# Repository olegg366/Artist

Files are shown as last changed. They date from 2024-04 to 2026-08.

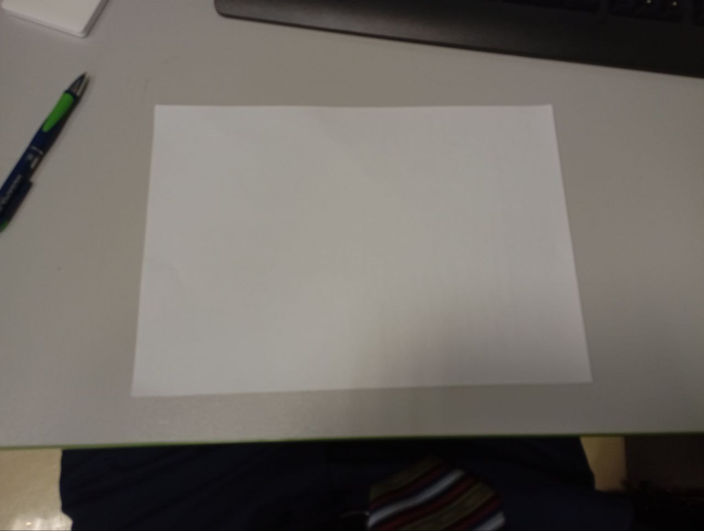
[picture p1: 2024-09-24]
images/paper1.jpg

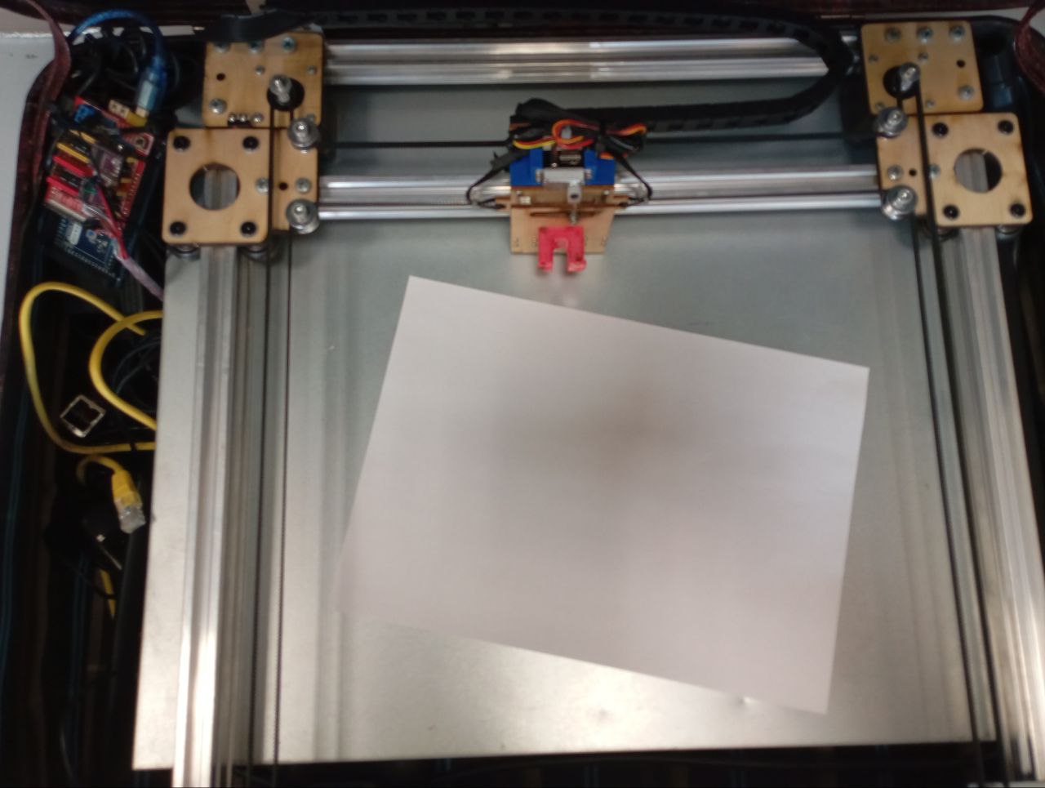
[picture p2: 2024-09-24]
images/paper.jpg

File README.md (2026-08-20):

# Робот-художник с искусственным интеллектом

Робот на базе координатного плоттера (кинематика H-bot), который распознаёт жесты и голос пользователя, генерирует изображение по наброску и текстовой подсказке (Stable Diffusion + ControlNet) и рисует его маркером на бумаге. Устройство собрано в корпусе чемодана.

Проект выполнен в рамках Всероссийской олимпиады школьников (профиль «Робототехника», технология/труд), ГБНОУ «Президентский ФМЛ №239». Полная пояснительная записка — в [`docs/`](docs).

---

## Идея

Пользователь рисует пальцем в воздухе набросок и произносит тему открытки. Робот:

1. по видео с камеры распознаёт кисть руки и жесты (без каких-либо контроллеров/перчаток — только компьютерное зрение);
2. переводит траекторию пальца в линию на холсте;
3. распознаёт голосовую подсказку и переводит её на английский;
4. генерирует по наброску и тексту 3 варианта изображения нейросетью img2img (Stable Diffusion 1.5 + ControlNet-Scribble);
5. превращает выбранное растровое изображение в непрерывную траекторию заливки контуров, которую физически можно нарисовать одним маркером;
6. рисует получившуюся открытку на листе А5 плоттером, отслеживая, не мешает ли этому процессу рука человека в рабочей зоне.

В проекте задействованы: компьютерное зрение реального времени, классификация жестов собственной нейросетью, генеративная модель (Stable Diffusion), C++-модуль для расчёта траектории закраски растра, интеграция C++/Python через `ctypes`, прошивка ЧПУ (Marlin) и GUI на tkinter.

---

## Аппаратная часть (кратко, для понимания контекста ПО)

Структурная электрическая схема — [`docs/Э1.png`](docs/Э1.png).

- **Вычислительный блок**: Intel Core i5, NVIDIA GeForce RTX 3060 (12 ГБ VRAM, обязательна для инференса Stable Diffusion в разумное время), подключена через выносной модуль (ADT-Link UT3G, Thunderbolt/PCIe extender) — компьютер и видеокарта физически разнесены внутри чемодана.
- **Плоттер**: рама на алюминиевом конструкционном профиле, кинематика **H-bot** (позаимствована и адаптирована из открытой 3D-модели принтера, ось Z удалена — печатающая головка держит маркер и сервопривод его подъёма/опускания), 2 шаговых мотора Nema17 (42SHDC3025-24b) через драйверы DRV8825.
- **Контроллер плоттера**: Arduino Mega + Protoneer CNC Shield V3, прошивка — форк **Marlin** (см. [`Marlin/`](Marlin)), команды отправляются по serial в формате G-code.
- **Определение уровня маркера**: оптический концевой выключатель + автокалибровка угла сервопривода (см. `Plotter.calibrate_servo` в `plotter.py`).
- **Зрение**: 2 камеры Logitech HD 1080p (одна следит за рукой пользователя, другая — за рабочей зоной плоттера/бумагой), RTSP/локальный видеопоток.
- **Питание**: аккумулятор 6S1P 16000 мАч + понижающие преобразователи напряжения.
- Механика и корпус спроектированы в КОМПАС-3D (`models/`, `plans/`, `Machine.stp`), детали — лазерная резка фанеры + 3D-печать.

---

## Структура ПО

Весь код, кроме одного модуля траектории, написан на **Python**; вычислительно критичный модуль генерации траектории заливки — на **C++**, скомпилирован в разделяемую библиотеку и вызывается из Python через `ctypes`. Такое разделение осознанное: ИИ-части нужна простота интеграции с экосистемой ML (PyTorch/TensorFlow/Keras), а геометрическому алгоритму — сырая производительность и доступ к параллелизму GPU.

### Модуль жестового управления

| Файл | Назначение |
|---|---|
| `gesture_recognizer.py` | Отдельный процесс: получает кадры с камеры, прогоняет через **MediaPipe HandLandmarker** (21 ключевая точка кисти) и через собственную обученную сеть-классификатор жестов. |
| `mlmodels/static.keras`, `convert_tensorrt.py` | Классификатор жестов: `Conv1D → Conv1D → Dense`, обучен на 20 эпохах на собственном датасете (см. `gen_ds.py`, `dataset/*.npy` — записи координат ключевых точек для жестов `open`/`ok`/`up`/`dislike`, собраны покадровым разбором отснятого видео). Дополнительно оптимизирован через **TensorRT SDK** (`convert_tensorrt.py`, `mlmodels/static_tftrt/`) для ускорения инференса на GPU. |
| `commander.py` | Конечный автомат высокого уровня, интерпретирующий последовательность жестов в действия: `Thumb_Up` — начать/закончить рисование или подтвердить выбор («да» в диалогах), `Thumb_Down` — отклонить вариант («нет»), `Pointing_Up` — переместить курсор, «щипок» большого и указательного пальца (порог по отношению межпальцевого расстояния к длине пальца) — «зажать» и вести линию (жест `Click` определяется отдельно от ML-классификатора чисто геометрически), `Open_Palm` ×2 — очистить холст. |
| `utilites.py` | Общие геометрические функции (расстояние между landmark'ами, отрисовка скелета кисти, линейная интерполяция координат камера → экран). |

Межпроцессное взаимодействие построено на `multiprocessing.Process/Queue/Value`: захват видео, распознавание жестов, генеративная нейросеть и GUI выполняются в **параллельных процессах**, синхронизированных через очереди и разделяемые примитивы, — иначе тяжёлый инференс диффузионной модели «заморозил» бы интерфейс.

Отдельная деталь: координата указательного пальца транслируется не напрямую в canvas, а в системный курсор мыши через `pyautogui` (`Commander.move`), а сама линия на холсте рисуется по отдельным командам (`set_start`/`draw_line`/`end_line`), отправляемым в GUI-процесс через очередь — canvas в `interface.py` намеренно не подписан на нативные события мыши tkinter, вся отрисовка идёт только через этот канал.

### Голосовой ввод

Распознавание речи и перевод реализованы прямо в `Commander.listen()` (`commander.py`): запись с микрофона через `speech_recognition`, распознавание русской речи (Google Speech API), перевод на английский через `googletrans` — для передачи в англоязычную по природе модель Stable Diffusion. Подтверждение распознанной фразы также идёт жестами (`Thumb_Up`/`Thumb_Down`) через тот же `move_while`, то есть голосовой и жестовый каналы переиспользуют одну и ту же логику ожидания. В репозитории также есть `google_speech.py` с похожей автономной функцией `recognize_and_translate` — в текущем пайплайне она не импортируется и не используется, судя по всему это более ранняя версия того же функционала.

### Генеративная нейросеть

`generator.py` — управление диффузионным пайплайном через библиотеку **`diffusers`**:

- **Stable Diffusion 1.5** + **ControlNet-Scribble** (`lllyasviel/sd-controlnet-scribble`) — набросок пользователя используется как структурное условие (contour-conditioning) генерации, а не просто как затравка, что даёт предсказуемую композицию итоговой картинки;
- планировщик **UniPCMultistepScheduler** — ускоренный сэмплер, позволяющий получить качественный результат за меньшее число шагов диффузии;
- **DeepCache** — кэширование промежуточных активаций UNet между шагами денойзинга для ускорения инференса;
- **tomesd** (Token Merging for Stable Diffusion) — слияние похожих токенов внимания, снижение вычислительной нагрузки без заметной потери качества;
- **xFormers** memory-efficient attention + `channels_last` memory format для UNet/VAE — оптимизация под конкретную архитектуру GPU;
- инференс выполняется на CUDA, весь пайплайн запущен в отдельном процессе, прогресс диффузии (шаг за шагом) прокидывается обратно в GUI через очередь для прогресс-бара.

Набор оптимизаций (DeepCache, tomesd, xFormers) выбран, чтобы уложить генерацию в приемлемое время на одной видеокарте с 12 ГБ видеопамяти при демонстрации вживую.

### Определение бумаги в рабочей зоне

`detect_paper.py` — компьютерное зрение поверх OpenCV/scikit-image: HSV-маскирование по цвету реперных зелёных меток на листе, поиск контуров, `minAreaRect` + сопоставление углов, перспективная трансформация (`warpPerspective`) для приведения снятого листа к прямоугольнику, повторное выделение внутренней зелёной рамки на выровненном изображении фильтром Канни для точного определения границ печатной области.

### Перевод изображения в траекторию плоттера

**Постановка задачи**: дано растровое бинарное изображение контуров (после `canny` + бинарная дилатация в `drawer.py`/`utilites.py`), нужно построить один непрерывный путь маркера конечной толщины `d`, который закрасит все контурные пиксели, минимизируя количество отрывов пера и лишних перемещений. По формулировке это близко к задачам покрытия зоны обхода (area coverage / Chinese postman) на нерегулярной области, для которых в общем случае нет простого точного решения за разумное время, поэтому используется эвристика.

**Алгоритм** (`trajectory.cpp`, экспортируется как `extern "C"` для вызова из Python):

1. Случайно выбирается стартовая точка, вокруг которой в радиусе `d/2` нет ни закрашенных, ни выходящих за рисунок точек.
2. Между текущей и следующей точкой строится путь (`get_path`), и вдоль всего пути закрашивается «дорожка» шириной `d` (имитация толщины реального маркера) — заливка выполняется BFS-подобным обходом (`fill_area`) с деками и посещённостью, а не наивным перебором пикселей.
3. Далее ищется следующая точка на расстоянии `d + 1` от текущей, удовлетворяющая тому же условию; если такой нет — берётся случайная валидная точка на изображении; если и такой нет — условие ослабляется (достаточно не выходить за границы исходной маски).
4. Цикл повторяется, пока не останется незакрашенных пикселей.
5. Результат — последовательность координат с маркерами разрывов (`±1e9`), которую `plotter.py` превращает в G-code, сшивая соседние фрагменты и вставляя команды подъёма/опускания пера между несвязными участками.

**Производительность и GPU-параллелизм.** При обработке реалистичных изображений число точек достаточно велико, чтобы наивная реализация на C++ работала медленно. Часть циклов переписана с использованием алгоритмов `std::execution`/`stdpar` (C++17), и модуль компилируется компилятором `nvc++` из NVIDIA HPC SDK с флагами `-stdpar -gpu=managed,cuda...,cc...` — стандартные алгоритмы STL (`transform`, `reduce`, `any_of`) в этом случае выполняются на GPU без написания CUDA-кернелов вручную. По оценке из пояснительной записки, это даёт прирост скорости на порядок по сравнению с однопоточным CPU-вариантом.

**Компиляция на лету.** `drawer.py::TrajectoryLib` сравнивает текущий исходник `trajectory.cpp` с сохранённой предыдущей версией (`lib/trajectory.prev`) и, если код изменился, перекомпилирует `.so`-библиотеку прямо во время работы программы (JIT-подобная схема разработки для C++/GPU кода).

**Мост Python ↔ C++.** Через `ctypes.CDLL` и `numpy.ctypeslib.ndpointer` с явной типизацией указателей (2D/3D массивы `float128`/`int32`) — передача сырых NumPy-буферов в скомпилированную библиотеку без копирования и без обёрточных биндингов вроде pybind11/Cython (в проекте также есть отдельные эксперименты с Cython, см. `tests/test_cython/`).

### Управление плоттером и прошивка

- `plotter.py` — класс `Plotter(serial.Serial)`: отправка G-code по последовательному порту с построчным подтверждением (`ok\n`), автокалибровка угла сервопривода по срабатыванию концевого выключателя, расчёт задержек между командами по фактической скорости подачи, а также **параллельный процесс безопасности** `HandChecker` — во время печати отдельный процесс детектирует руку человека в рабочей зоне через тот же MediaPipe-детектор и ставит печать на паузу, если пользователь потянулся к плоттеру.
- [`Marlin/`](Marlin) — используется прошивка **Marlin** (популярная прошивка для 3D-принтеров), сконфигурированная под кинематику **CoreXY/H-bot** и плату `PROTONEER_CNC_SHIELD_V3`, с урезанной осью Z (заменена на сервопривод пера).

### Интерфейс пользователя

`interface.py` — GUI на `tkinter`: собственные виджеты со скруглёнными углами и кастомной отрисовкой на `Canvas` (`RoundedFrame`/`RoundedButton`, ручное построение сглаженных многоугольников, авто-перенос текста по ширине виджета), полноэкранное окно с превью видео с камеры, индикатором состояния рисования (цветовой светофор), прогресс-баром генерации, попапом выбора толщины линии и блоком пошаговой инструкции по жестам для новых пользователей. Все тяжёлые операции (распознавание, генерация, печать) выполняются в фоновых процессах и общаются с GUI-процессом строго через очереди команд (`commands_queue`), что нужно, поскольку `tkinter` не является потокобезопасным.

### Обучение и вспомогательные ноутбуки

- `model.ipynb` — подготовка датасета жестов и обучение классификатора (`Conv1D`-архитектура на Keras/TensorFlow, `L2`-регуляризация), там же — эксперименты с настройкой пайплайна Stable Diffusion.
- `gen_ds.py` — сбор обучающей выборки: покадровое считывание landmark'ов руки с камеры и сохранение в `.npy`.
- `paper.ipynb`, `convert.ipynb` — вспомогательные эксперименты (отладка детекции бумаги, конвертации моделей).
- `draw_logo.py` — служебный скрипт печати заранее заданных изображений (например, логотипа) в обход основного пайплайна жестового ввода — использовался для тестирования плоттера отдельно от ИИ-части.

---

## Особенности реализации

- Захват видео, распознавание жестов, генерация изображения и GUI выполняются в отдельных процессах (`multiprocessing`), обмен данными — через очереди и разделяемые значения, а не напрямую.
- В проекте сочетаются разные модели вычислений: CUDA-инференс нейросетей (PyTorch/TensorRT), GPU-параллелизм через `stdpar`/`nvc++` в C++-модуле траектории, обычный CPU-код для CV и GUI.
- Обмен данными между Python и C++ идёт напрямую через `ctypes` и `numpy.ctypeslib.ndpointer`, без промежуточных биндинг-генераторов (pybind11/Cython); типы указателей и layout памяти согласуются вручную.
- Во время печати параллельно работает CV-детектор руки в рабочей зоне (`HandChecker`), который ставит плоттер на паузу при вторжении.
- Заливка контура маркером конечной толщины реализована собственным эвристическим алгоритмом (жадный обход ближайшей допустимой точки с постепенным ослаблением условий при тупике), а не сторонней библиотекой.
- Угол подъёма сервопривода пера определяется автокалибровкой по концевому выключателю при каждом запуске, а не задаётся константой в коде.

---

## Технологический стек

**Компьютерное зрение / ML:** MediaPipe (HandLandmarker), TensorFlow/Keras, TensorRT SDK, OpenCV, scikit-image (Canny, морфология, `regionprops`).

**Генеративный ИИ:** PyTorch, `diffusers` (Stable Diffusion 1.5, ControlNet), `tomesd`, `DeepCache`, `xFormers`, CUDA.

**Голос:** `SpeechRecognition` (Google Speech API), `googletrans`.

**Высокопроизводительные вычисления:** C++17, `std::execution`/`stdpar`, NVIDIA HPC SDK (`nvc++`), CUDA, `ctypes`.

**Механика/прошивка:** Marlin firmware, G-code, `pyserial`, Arduino Mega + CNC Shield.

**Интерфейс/инфраструктура:** `tkinter`, `multiprocessing`, NumPy, `pyautogui`, КОМПАС-3D (проектирование, вне репозитория кода).

---

## О запуске

Проект **не является «plug-and-play» приложением** и не предназначен для запуска на произвольной машине без соответствующего физического робота. Он поднимался в окружении, куда были заранее установлены и состыкованы по версиям, в частности:

- CUDA Toolkit и драйверы NVIDIA под конкретную видеокарту;
- PyTorch + `diffusers`/`transformers`/`accelerate` (с загрузкой весов Stable Diffusion 1.5 и ControlNet-Scribble из HuggingFace);
- TensorFlow/Keras + TensorRT SDK;
- MediaPipe с моделью `hand_landmarker.task`;
- NVIDIA HPC SDK (компилятор `nvc++`) для сборки C++/GPU-модуля траектории под конкретную вычислительную архитектуру GPU (`cc86`);
- OpenCV, scikit-image, `pyserial`, `SpeechRecognition`, `googletrans`, `pyautogui`, `webcolors` и другие Python-зависимости интерфейса;
- прошитая плата Arduino Mega с Marlin, физически подключённая по serial, и подключённые камеры/микрофон.

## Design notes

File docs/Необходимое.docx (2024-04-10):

1) Профили:
  a) 20*20*43 (https://www.soberizavod.ru/catalog/seriya_20_v_paz/profil_konstruktsionnyy_v20kh20_bez_pokrytiya/)3 х2
  b) 20*40*492 (https://www.soberizavod.ru/catalog/seriya_20_v_paz/profil_konstruktsionnyy_v20kh40_bez_pokrytiya/) х2
  c) 20*20*423 (https://www.soberizavod.ru/catalog/seriya_20_v_paz/profil_konstruktsionnyy_v20kh20_bez_pokrytiya/) х1
2) Уголки:
  a) 60*60 6 отв (https://www.soberizavod.ru/catalog/g_obraznye_seriya_20/g_soedinitel_60kh60_paz_6_otv_6_l61/?sphrase_id=325903) х8
3) Пластины:
  a) 40*60 6 отв (https://www.soberizavod.ru/catalog/pryamougolnye_seriya_20/soedinitel_40kh60_paz_6_m49/?sphrase_id=325904) х4
  b) Part2 (печать)
  c) Carriage (печать)
  d) Head holder (печать)
4) Подшипники и ролики:
  a) Ролики (https://www.soberizavod.ru/catalog/standartnye_2/standartnyy_plastikovyy_rolik_dlya_v_paza_a172/) х13
  b) Подшипники (https://www.soberizavod.ru/catalog/dlya_standartnykh_rolikov_1/podshipnik_dlya_standartnykh_rolikov_5_16_625zz_a181/) 23x
5) Шкивы:
  a) GT2 ширина 10 отверстие 5 (https://roboparts.ru/catalog/komplektuyushchie_dlya_3d_printera/shkivy/gt2-10mm-20-zubov-d-5mm/) х2
  b) GT2 ширина 10 отверстия 5 без скруглений (https://roboparts.ru/catalog/komplektuyushchie_dlya_3d_printera/shkivy/shkiv-gt2-v2-20-zubov-10mm-d-5mm/) х2
  c) GT2 ширина 6 отверстие 5 гладкие (https://roboparts.ru/catalog/komplektuyushchie_dlya_3d_printera/shkivy/rolik-gt2-6mm-h-type/) х4
6) Моторы: Nema17 х2
7) Крепление:
  a) Т-болт х48
  b) Т-гайки М5 (https://www.soberizavod.ru/catalog/t_bolty_i_t_gayki_paz_6/t_gayka_m5_paz_6_a130/) 60x
  c) Т-гайки М4 (https://www.soberizavod.ru/catalog/t_bolty_i_t_gayki_paz_6/t_gayka_m4_paz_6_a129/) 10х
  d) Т-гайки М3 (https://www.soberizavod.ru/catalog/t_bolty_i_t_gayki_paz_6/t_gayka_m3_paz_6_a128/) 10х
  e) Винты для Т-гаек (https://www.soberizavod.ru/catalog/m5_2/vint_s_polukrugl_gol_i_vn_shestigr_otsink_m5_kh_8_iso_7380_1_a523/) 60x
  f) Винты для крепления шкивов (https://www.soberizavod.ru/catalog/m5_1/vint_tsilindr_s_vnutrennim_shest_m5_kh_25_din_912_k83/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) 10х
  g) Шайбы 5 (https://www.soberizavod.ru/catalog/obychnaya_shayba/shayba_5_otsink_din_125_k44/?sphrase_id=336375) 30х
  h) Шайбы для роликов (https://www.soberizavod.ru/catalog/shayby_vysokotochnye_distantsionnye_1/vysokotochnaya_distantsionnaya_shayba_5_mm_a211/) х12
  i) Втулки для роликов (https://www.soberizavod.ru/catalog/vtulki_distantsionnye_dlya_vinta_m5/distantsionnaya_vtulka_5kh6_mm_a201/) х15
  j) Винты для роликов (https://www.soberizavod.ru/catalog/vinty_m5_s_nizkoy_golovkoy/vint_s_ploskoy_golovkoy_i_vnut_shestigrannikom_m5kh30_a144/) х15
  k) Самоконтрящиеся гайки (https://www.soberizavod.ru/catalog/gayki_m5/samokontryashchayasya_gayka_m5_a229/) х15
  l) Эксцентрики (https://www.soberizavod.ru/catalog/eksttsentriki/standartnyy_ekstsentrik_6_mm_dlya_vinta_m5_a195/) х15
  m) Ещё шайбы для роликов (https://www.soberizavod.ru/catalog/shayby_vysokotochnye_distantsionnye_1/vysokotochnaya_distantsionnaya_shayba_5_mm_a137/) х25
8) Драйверы: DFRobot Stepper motor shield
9) Arduino Mega
10) Ремни

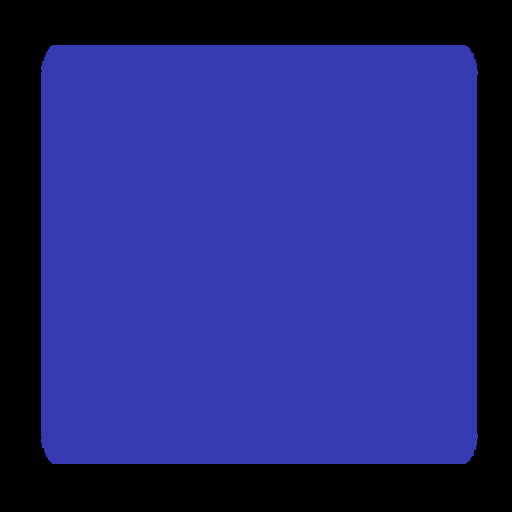
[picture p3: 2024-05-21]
images/square.png

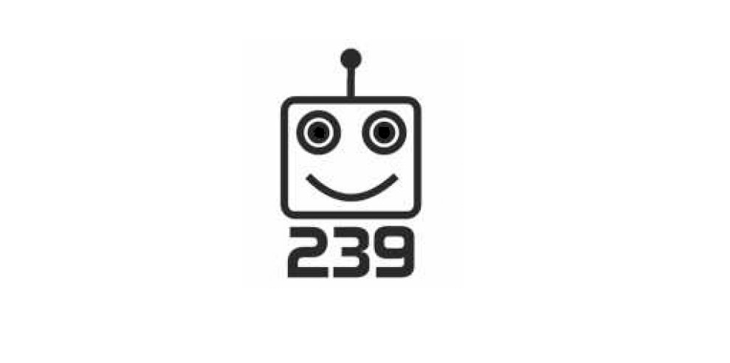
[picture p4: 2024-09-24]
images/robot.png

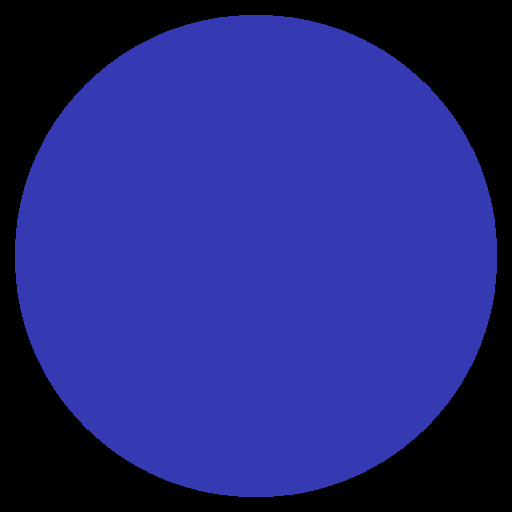
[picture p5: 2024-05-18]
images/circle.png

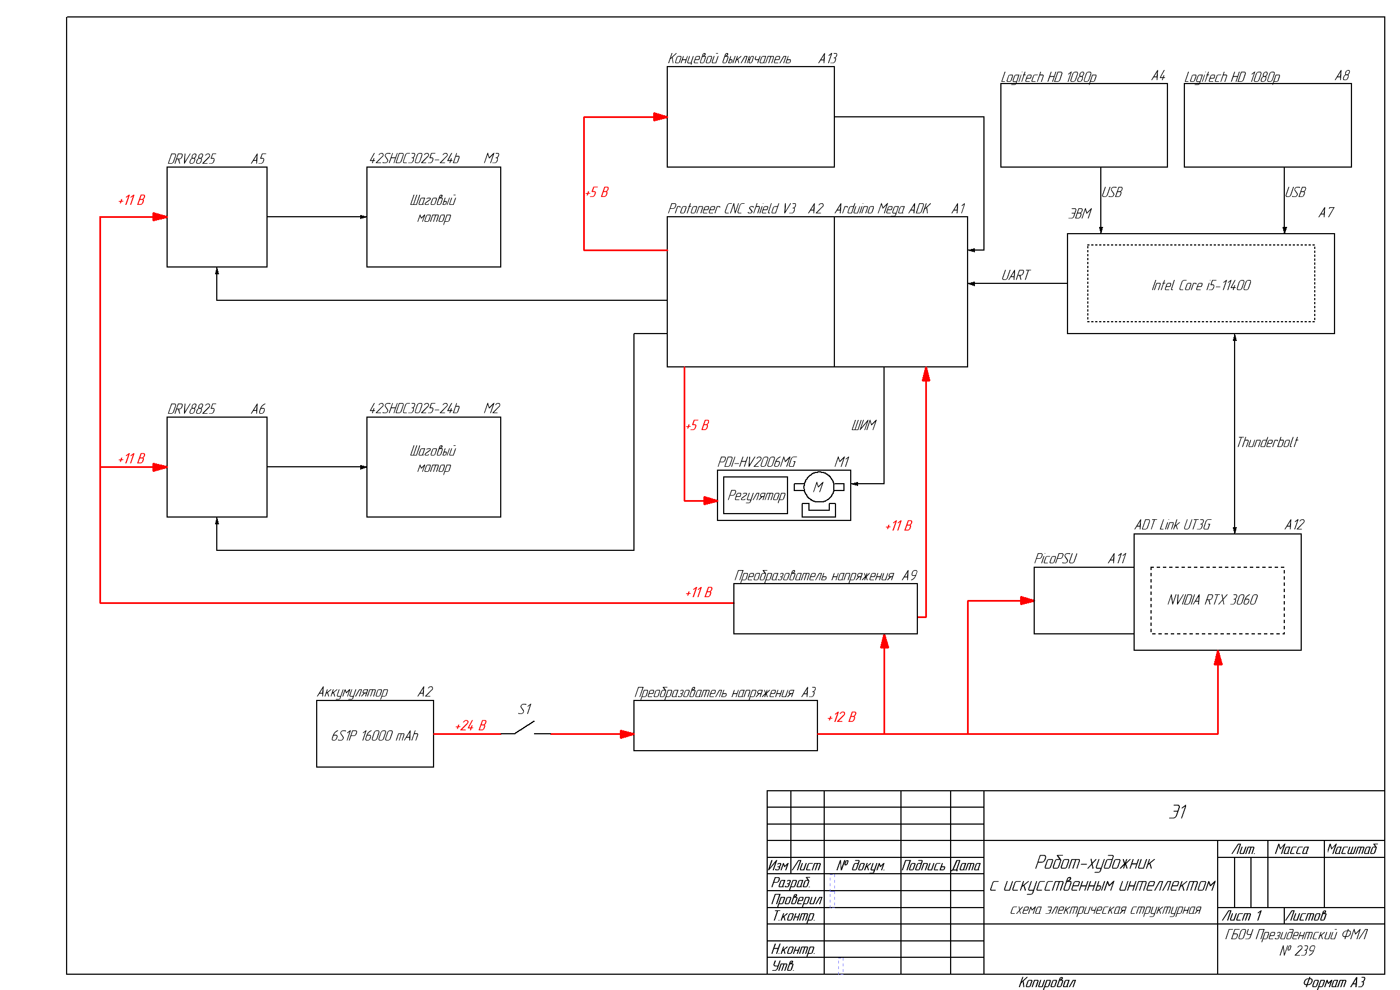
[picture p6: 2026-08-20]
docs/Э1.png

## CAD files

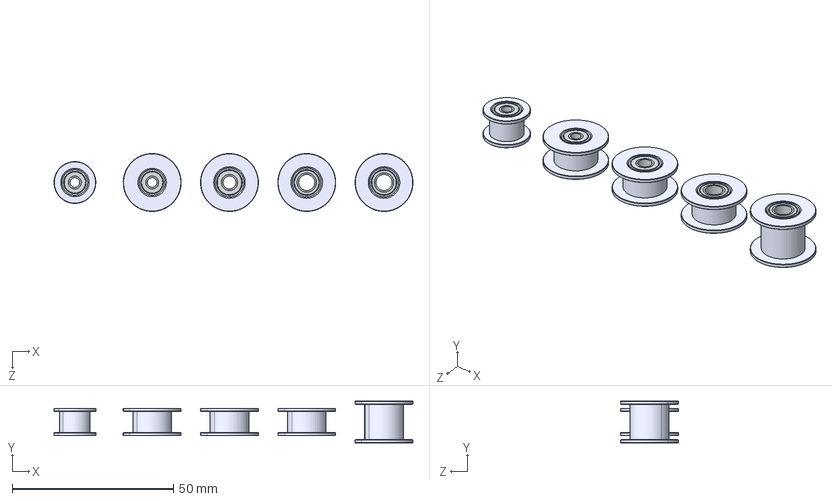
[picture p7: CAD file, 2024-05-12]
models/STEP/GT2 Idler Pulley, Configurable, Pulleys Lined Up in Assembly.STEP
111.5 x 13.0 x 18.0 mm
Body, GT2 Idler Pulley, Configurable_16T W6 B3 Without T
Bearing Outer Ring, GT2 Idler Pulley, Configurable_3 mm Bore x 4
Bearing Inner Ring, GT2 Idler Pulley, Configurable_3 mm Bore x 4
Bearing Seal, GT2 Idler Pulley, Configurable_3 mm Bore x 8
Bearing Ball, GT2 Idler Pulley, Configurable_2 mm x 40
Body, GT2 Idler Pulley, Configurable_20T W6 B3 Without T
Body, GT2 Idler Pulley, Configurable_20T W6 B4 Without T
Bearing Outer Ring, GT2 Idler Pulley, Configurable_4 mm Bore x 2
Bearing Inner Ring, GT2 Idler Pulley, Configurable_4 mm Bore x 2
Bearing Seal, GT2 Idler Pulley, Configurable_4 mm Bore x 4
Body, GT2 Idler Pulley, Configurable_20T W6 B5 Without T
Bearing Outer Ring, GT2 Idler Pulley, Configurable_5 mm Bore x 4
Bearing Inner Ring, GT2 Idler Pulley, Configurable_5 mm Bore x 4
Bearing Seal, GT2 Idler Pulley, Configurable_5 mm Bore x 8
Bearing Ball, GT2 Idler Pulley, Configurable_1.4 mm x 48
Body, GT2 Idler Pulley, Configurable_20T W10 B5 Without T

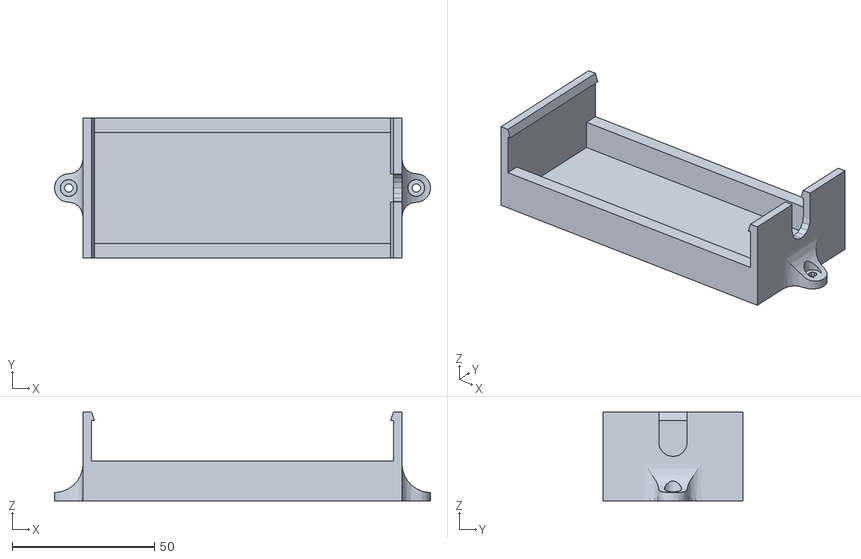
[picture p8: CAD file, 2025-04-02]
models/Print/Крепление хаба.stl
132.0 x 49.0 x 31.2

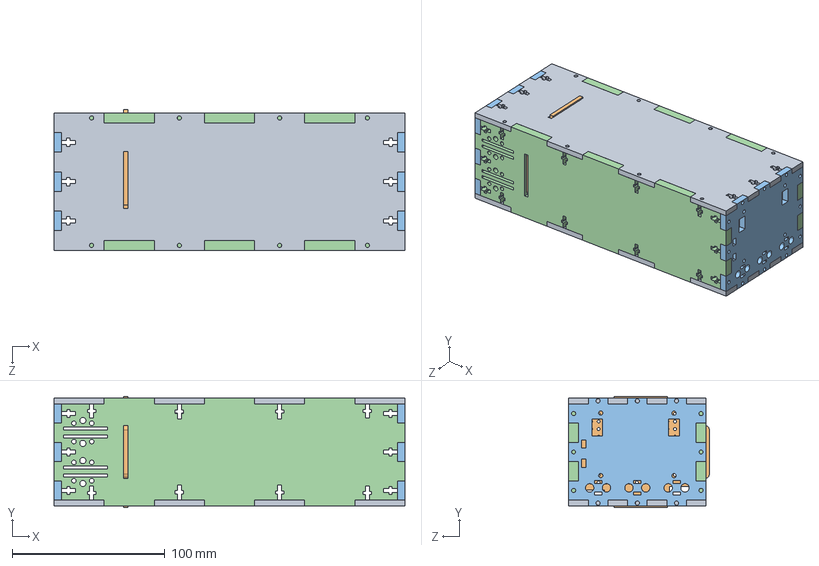
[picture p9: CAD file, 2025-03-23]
models/STEP/KUKA_KiPo 6S1P 16000mAh.STEP
230.0 x 73.0 x 92.2 mm
BottomPanel x 2
Repaired_FrontPanel_-00 x 2
Repaired_SidePanel_-00 x 2

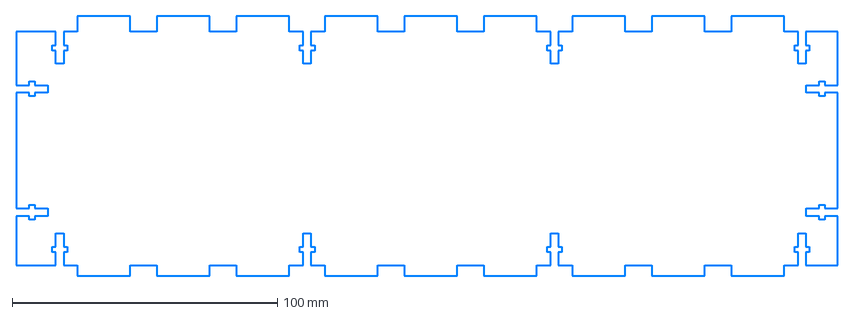
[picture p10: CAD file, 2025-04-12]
plans/Боковая стенка 6.dxf
310.0 x 98.0 mm

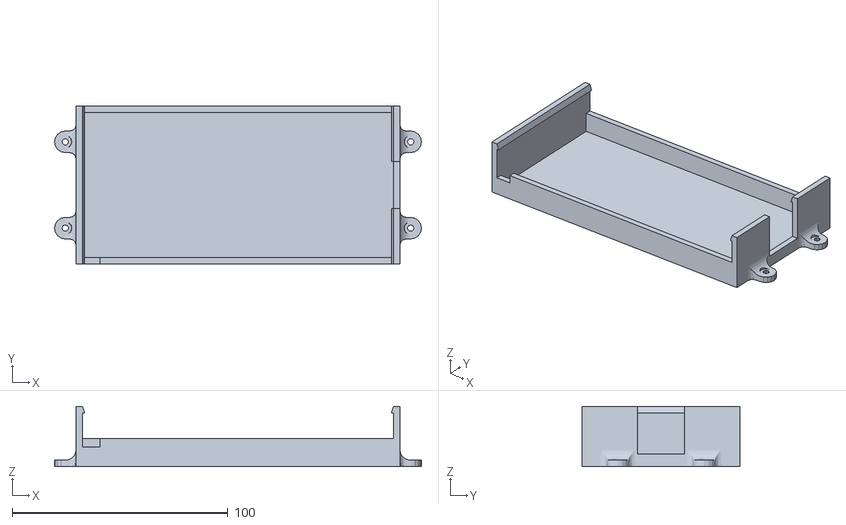
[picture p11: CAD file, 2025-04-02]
models/Print/Крепление блока питания ноутбука.stl
170.0 x 73.0 x 27.9

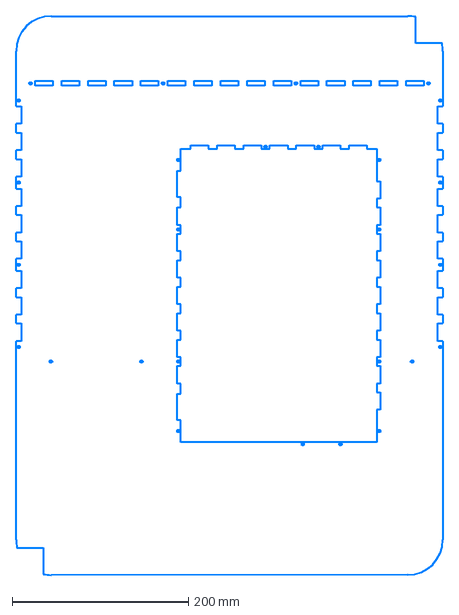
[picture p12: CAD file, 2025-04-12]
plans/Верхняя пластина.dxf
485.0 x 635.0 mm

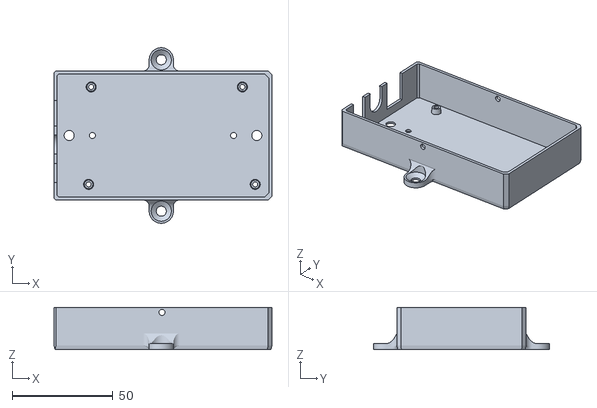
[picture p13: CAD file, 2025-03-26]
models/Print/Base.stl
108.0 x 87.0 x 21.0

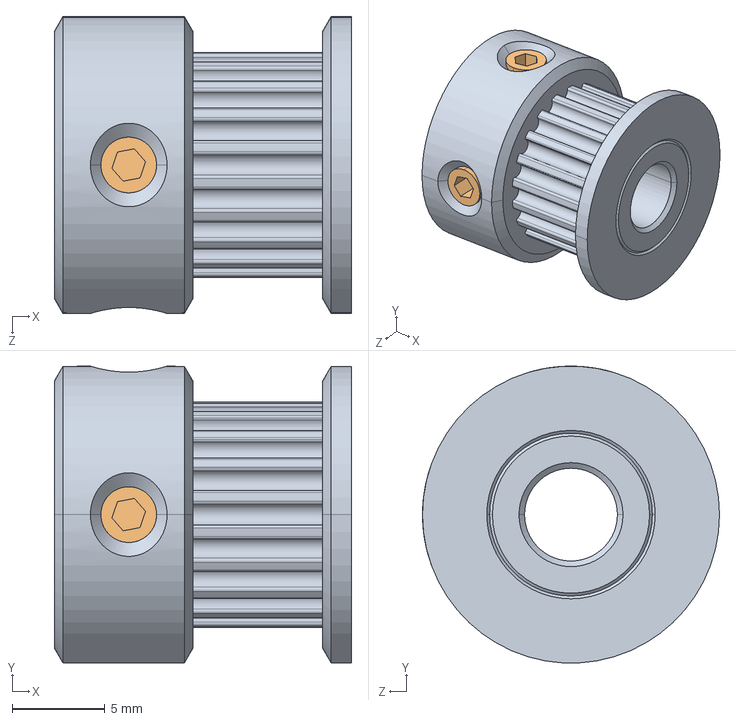
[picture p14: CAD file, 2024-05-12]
models/STEP/GT2_20T.STEP
16.0 x 16.0 x 16.0 mm

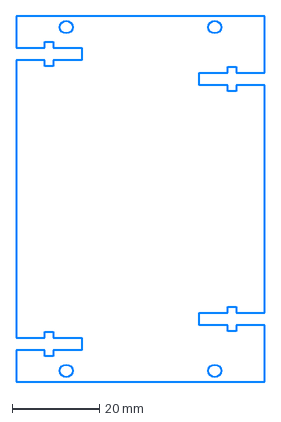
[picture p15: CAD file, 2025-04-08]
plans/Крепление стабилизатора 4.dxf
57.0 x 84.0 mm

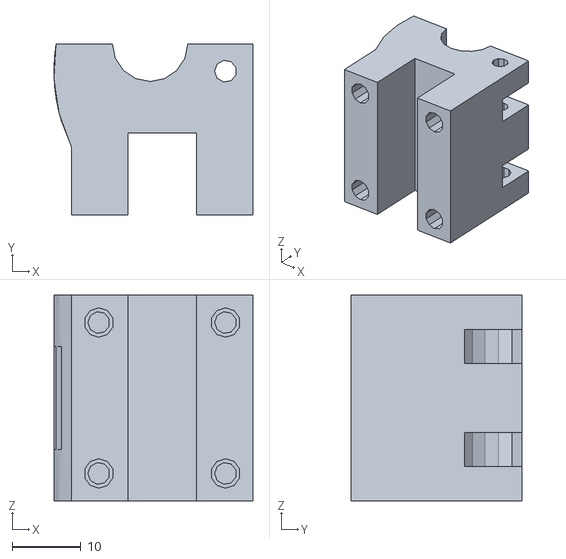
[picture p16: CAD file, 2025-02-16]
models/Print/Держатель маркера 2_0.stl
29.0 x 25.0 x 30.0

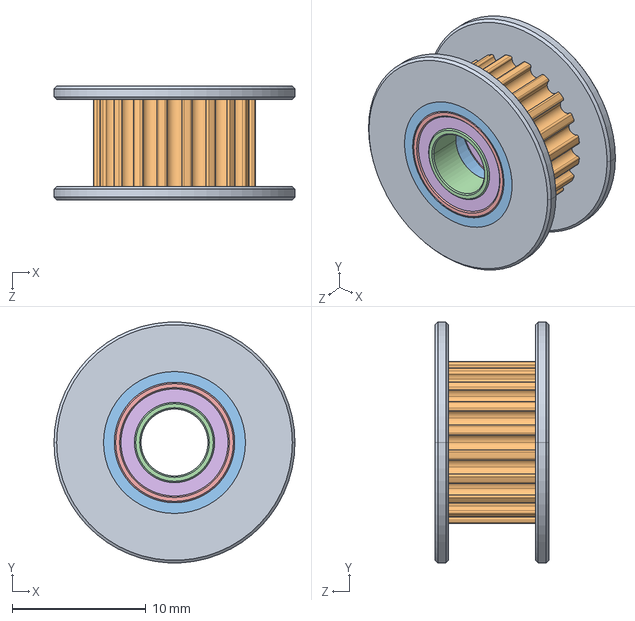
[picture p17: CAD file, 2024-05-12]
models/STEP/GT2_20T_kladka_dz.STEP
18.0 x 18.0 x 8.50 mm

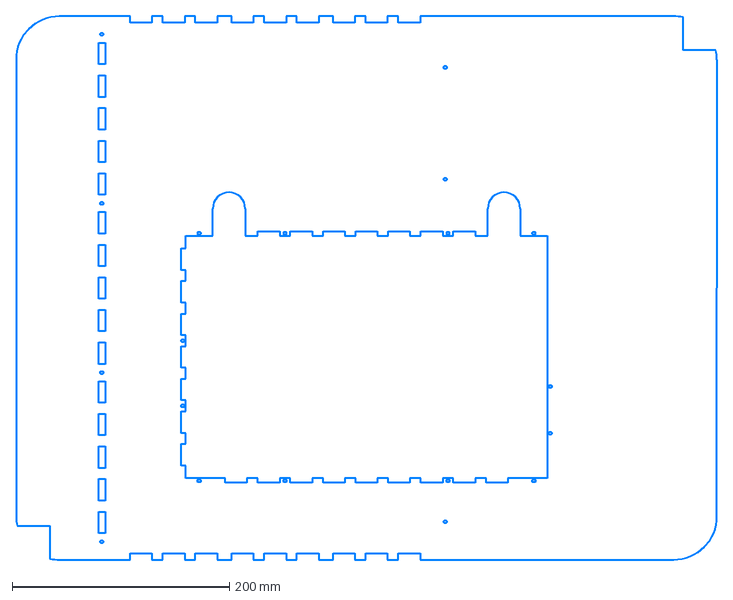
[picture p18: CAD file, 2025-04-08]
plans/Нижняя пластина 6.dxf
645.0 x 500.0 mm

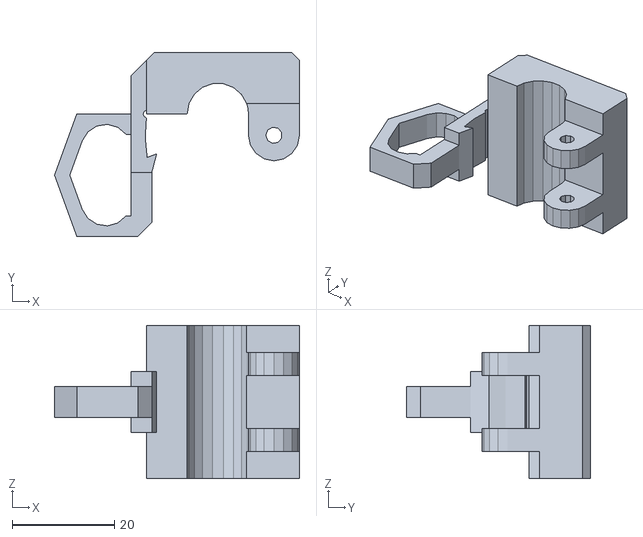
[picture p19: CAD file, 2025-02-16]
models/Print/Защелка для держателя.stl
48.0 x 36.0 x 30.0

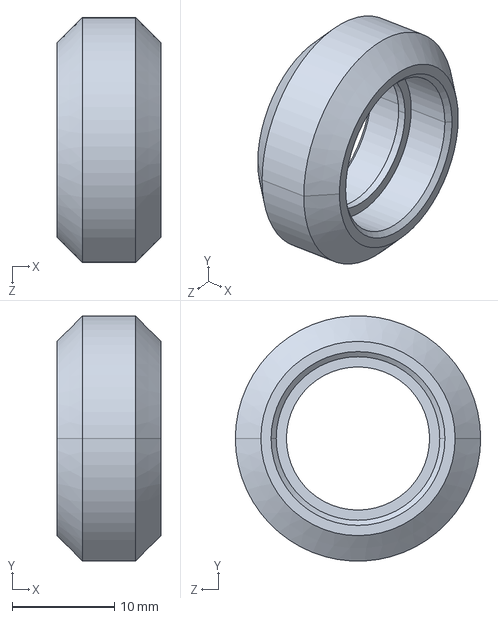
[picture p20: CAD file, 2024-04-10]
models/STEP/A172-Standartnyy-plastikovyy-rolik-dlya-V_paza.STEP
10.2 x 24.0 x 24.0 mm

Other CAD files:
plans/Крепление стабилизатора рахъем 4.dxf
models/Print/Держатель маркера.stl
models/STEP/A195-Standartnyy-ekstsentrik-6-mm_-dlya-vinta-M5.STEP
plans/Боковое крепление видеокарты 4.dxf
models/Print/Крепление для держателя.stl
models/Print/Пластина для сервопривода.stl
models/STEP/A137-Vysokotochnaya-prokladka-_-5_3-_-8.STEP
models/STEP/A181-Podshipnik-625rs_-_-5-_-16.STEP
models/STEP/A201-Distantsionnaya-vtulka-5kh6-mm.STEP
models/STEP/A211-Vysokotochnaya-distantsionnaya-shayba-5-mm.STEP
models/STEP/M49-Soedinitel-40kh60.STEP
plans/Боковое крепление стабилизатора 4.dxf
plans/Держатель_головы.dxf
plans/Держатель_каретки.dxf
plans/Длинная коробка 4.dxf
plans/Длинная коробка петли 4.dxf
plans/Дно корпуса 6.dxf
plans/Каретка-втулки 3мм.dxf
plans/Каретка.dxf
plans/Каретка_эксцентрики 3мм.dxf
plans/Коробка нижняя 4.dxf
plans/Короткая коробка лево 4.dxf
plans/Короткая коробка право 4.dxf
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

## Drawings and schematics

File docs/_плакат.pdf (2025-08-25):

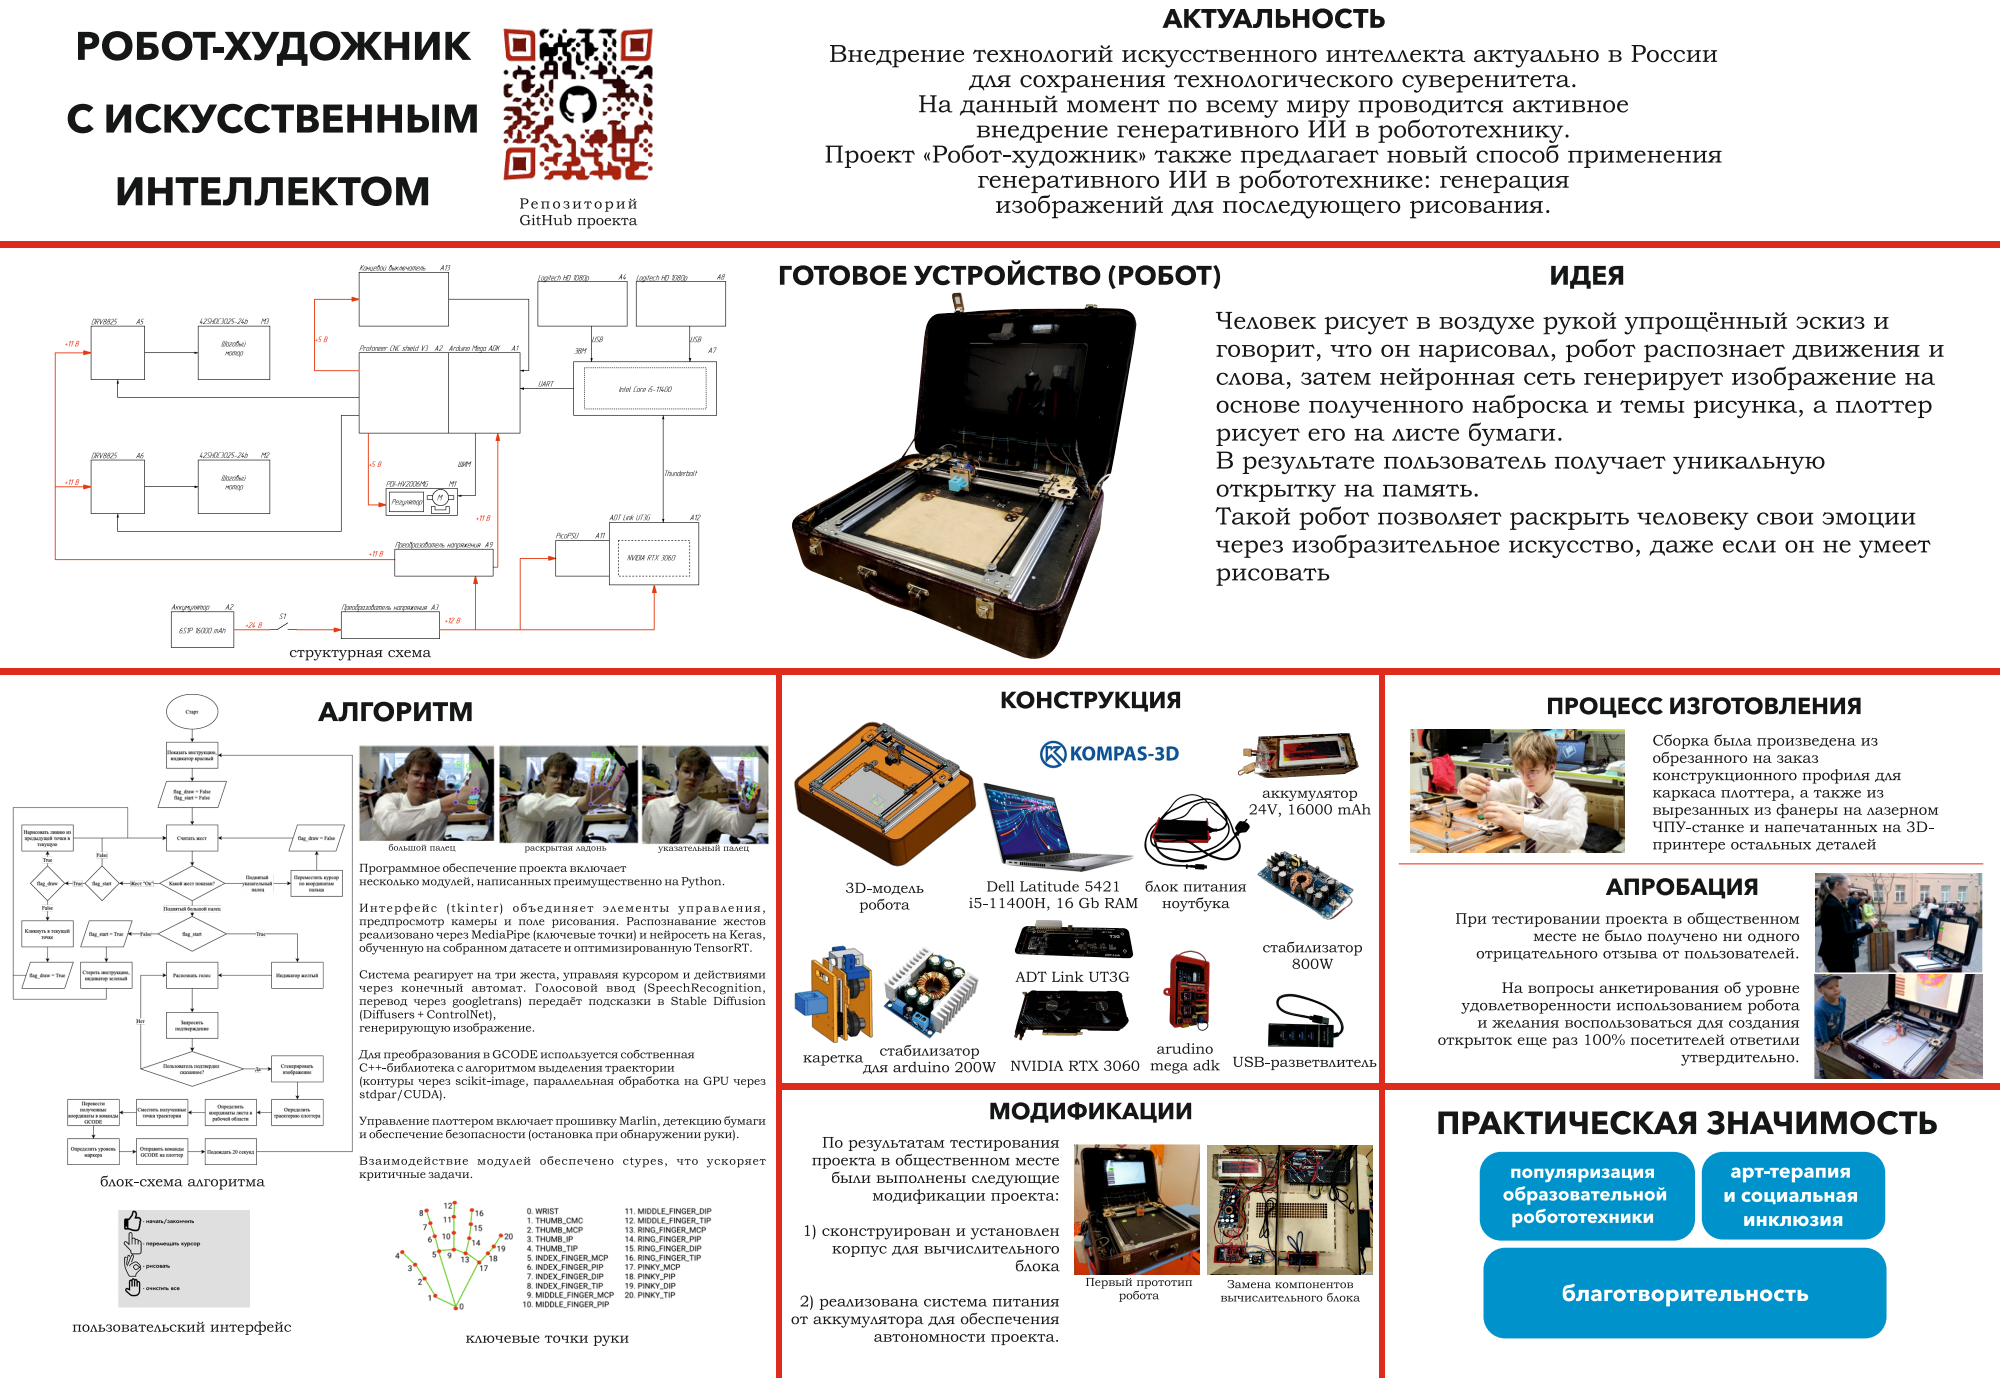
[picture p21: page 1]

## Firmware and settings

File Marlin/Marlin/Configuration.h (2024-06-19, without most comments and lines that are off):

#pragma once
#define CONFIGURATION_H_VERSION 02010300
#define STRING_CONFIG_H_AUTHOR "(none, default config)" // Who made the changes.
  #define MOTHERBOARD BOARD_PROTONEER_CNC_SHIELD_V3
#define SERIAL_PORT 0
#define BAUDRATE 115200
#define X_DRIVER_TYPE  DRV8825
#define Y_DRIVER_TYPE  DRV8825
#define EXTRUDERS 0
#define DEFAULT_NOMINAL_FILAMENT_DIA 1.75
#define TEMP_SENSOR_0 0
#define TEMP_SENSOR_1 0
#define TEMP_SENSOR_2 0
#define TEMP_SENSOR_3 0
#define TEMP_SENSOR_4 0
#define TEMP_SENSOR_5 0
#define TEMP_SENSOR_6 0
#define TEMP_SENSOR_7 0
#define TEMP_SENSOR_BED 0
#define TEMP_SENSOR_PROBE 0
#define TEMP_SENSOR_CHAMBER 0
#define TEMP_SENSOR_COOLER 0
#define TEMP_SENSOR_BOARD 0
#define TEMP_SENSOR_SOC 0
#define TEMP_SENSOR_REDUNDANT 0
#define DUMMY_THERMISTOR_998_VALUE  25
#define DUMMY_THERMISTOR_999_VALUE 100
#if TEMP_SENSOR_IS_MAX_TC(0)
  #define MAX31865_SENSOR_OHMS_0      100 // (Ω) Typically 100 or 1000 (PT100 or PT1000)
  #define MAX31865_CALIBRATION_OHMS_0 430 // (Ω) Typically 430 for Adafruit PT100; 4300 for Adafruit PT1000
#endif
#if TEMP_SENSOR_IS_MAX_TC(1)
  #define MAX31865_SENSOR_OHMS_1      100
  #define MAX31865_CALIBRATION_OHMS_1 430
#endif
#if TEMP_SENSOR_IS_MAX_TC(2)
  #define MAX31865_SENSOR_OHMS_2      100
  #define MAX31865_CALIBRATION_OHMS_2 430
#endif
#if HAS_E_TEMP_SENSOR
  #define TEMP_RESIDENCY_TIME         10  // (seconds) Time to wait for hotend to "settle" in M109
  #define TEMP_WINDOW                  1  // (°C) Temperature proximity for the "temperature reached" timer
  #define TEMP_HYSTERESIS              3  // (°C) Temperature proximity considered "close enough" to the target
#endif
#if TEMP_SENSOR_BED
  #define TEMP_BED_RESIDENCY_TIME     10  // (seconds) Time to wait for bed to "settle" in M190
  #define TEMP_BED_WINDOW              1  // (°C) Temperature proximity for the "temperature reached" timer
  #define TEMP_BED_HYSTERESIS          3  // (°C) Temperature proximity considered "close enough" to the target
#endif
#if TEMP_SENSOR_CHAMBER
  #define TEMP_CHAMBER_RESIDENCY_TIME 10  // (seconds) Time to wait for chamber to "settle" in M191
  #define TEMP_CHAMBER_WINDOW          1  // (°C) Temperature proximity for the "temperature reached" timer
  #define TEMP_CHAMBER_HYSTERESIS      3  // (°C) Temperature proximity considered "close enough" to the target
#endif
#if TEMP_SENSOR_REDUNDANT
  #define TEMP_SENSOR_REDUNDANT_SOURCE    E1  // The sensor that will provide the redundant reading.
  #define TEMP_SENSOR_REDUNDANT_TARGET    E0  // The sensor that we are providing a redundant reading for.
  #define TEMP_SENSOR_REDUNDANT_MAX_DIFF  10  // (°C) Temperature difference that will trigger a print abort.
#endif
#define HEATER_0_MINTEMP   5
#define HEATER_1_MINTEMP   5
#define HEATER_2_MINTEMP   5
#define HEATER_3_MINTEMP   5
#define HEATER_4_MINTEMP   5
#define HEATER_5_MINTEMP   5
#define HEATER_6_MINTEMP   5
#define HEATER_7_MINTEMP   5
#define BED_MINTEMP        5
#define CHAMBER_MINTEMP    5
#define HEATER_0_MAXTEMP 275
#define HEATER_1_MAXTEMP 275
#define HEATER_2_MAXTEMP 275
#define HEATER_3_MAXTEMP 275
#define HEATER_4_MAXTEMP 275
#define HEATER_5_MAXTEMP 275
#define HEATER_6_MAXTEMP 275
#define HEATER_7_MAXTEMP 275
#define BED_MAXTEMP      150
#define CHAMBER_MAXTEMP  60
#define HOTEND_OVERSHOOT 15   // (°C) Forbid temperatures over MAXTEMP - OVERSHOOT
#define BED_OVERSHOOT    10   // (°C) Forbid temperatures over MAXTEMP - OVERSHOOT
#define COOLER_OVERSHOOT  2   // (°C) Forbid temperatures closer than OVERSHOOT
#define PIDTEMP           // See the PID Tuning Guide at https://reprap.org/wiki/PID_Tuning
#define PID_MAX  255      // Limit hotend current while PID is active (see PID_FUNCTIONAL_RANGE below); 255=full current
#define PID_K1     0.95   // Smoothing factor within any PID loop
    #define DEFAULT_Kp  22.20
    #define DEFAULT_Ki   1.08
    #define DEFAULT_Kd 114.00
#define MAX_BED_POWER 255 // limits duty cycle to bed; 255=full current
#define MAX_CHAMBER_POWER 255 // limits duty cycle to chamber heater; 255=full current
  #define PID_FUNCTIONAL_RANGE 10 // If the temperature difference between the target temperature and the actual temperature
#define PREVENT_COLD_EXTRUSION
#define EXTRUDE_MINTEMP 170
#define PREVENT_LENGTHY_EXTRUDE
#define EXTRUDE_MAXLENGTH 200
#define THERMAL_PROTECTION_HOTENDS // Enable thermal protection for all extruders
#define THERMAL_PROTECTION_BED     // Enable thermal protection for the heated bed
#define THERMAL_PROTECTION_CHAMBER // Enable thermal protection for the heated chamber
#define THERMAL_PROTECTION_COOLER  // Enable thermal protection for the laser cooling
#define COREXY
#define ENDSTOPPULLUPS
#define X_MIN_ENDSTOP_HIT_STATE HIGH
#define X_MAX_ENDSTOP_HIT_STATE HIGH
#define Y_MIN_ENDSTOP_HIT_STATE HIGH
#define Y_MAX_ENDSTOP_HIT_STATE HIGH
#define Z_MIN_ENDSTOP_HIT_STATE HIGH
#define Z_MAX_ENDSTOP_HIT_STATE HIGH
#define I_MIN_ENDSTOP_HIT_STATE HIGH
#define I_MAX_ENDSTOP_HIT_STATE HIGH
#define J_MIN_ENDSTOP_HIT_STATE HIGH
#define J_MAX_ENDSTOP_HIT_STATE HIGH
#define K_MIN_ENDSTOP_HIT_STATE HIGH
#define K_MAX_ENDSTOP_HIT_STATE HIGH
#define U_MIN_ENDSTOP_HIT_STATE HIGH
#define U_MAX_ENDSTOP_HIT_STATE HIGH
#define V_MIN_ENDSTOP_HIT_STATE HIGH
#define V_MAX_ENDSTOP_HIT_STATE HIGH
#define W_MIN_ENDSTOP_HIT_STATE HIGH
#define W_MAX_ENDSTOP_HIT_STATE HIGH
#define Z_MIN_PROBE_ENDSTOP_HIT_STATE HIGH
#define DEFAULT_AXIS_STEPS_PER_UNIT  { 80, 80 }
#define DEFAULT_MAX_FEEDRATE          { 300, 300 }
#define DEFAULT_MAX_ACCELERATION      { 1500, 1500 }
#define DEFAULT_ACCELERATION          1000    // X, Y, Z and E acceleration for printing moves
#define DEFAULT_RETRACT_ACCELERATION  1000    // E acceleration for retracts
#define DEFAULT_TRAVEL_ACCELERATION   1000    // X, Y, Z acceleration for travel (non printing) moves
  #define JUNCTION_DEVIATION_MM 0.013 // (mm) Distance from real junction edge
  #define JD_HANDLE_SMALL_SEGMENTS    // Use curvature estimation instead of just the junction angle
#define Z_MIN_PROBE_USES_Z_MIN_ENDSTOP_PIN
#define NOZZLE_TO_PROBE_OFFSET { 10, 10 }
#define PROBING_TOOL 0
#define PROBING_MARGIN 10
#define XY_PROBE_FEEDRATE (133*60)
#define Z_PROBE_FEEDRATE_FAST (4*60)
#define Z_PROBE_FEEDRATE_SLOW (Z_PROBE_FEEDRATE_FAST / 2)
#define Z_CLEARANCE_DEPLOY_PROBE   10 // (mm) Z Clearance for Deploy/Stow
#define Z_CLEARANCE_BETWEEN_PROBES  5 // (mm) Z Clearance between probe points
#define Z_CLEARANCE_MULTI_PROBE     5 // (mm) Z Clearance between multiple probes
#define Z_PROBE_ERROR_TOLERANCE     3 // (mm) Tolerance for early trigger (<= -probe.offset.z + ZPET)
#define Z_PROBE_LOW_POINT          -2 // (mm) Farthest distance below the trigger-point to go before stopping
#define X_ENABLE_ON 0
#define Y_ENABLE_ON 0
#define DISABLE_OTHER_EXTRUDERS   // Keep only the active extruder enabled
#define INVERT_X_DIR false
#define INVERT_Y_DIR true
#define INVERT_E0_DIR false
#define INVERT_E1_DIR false
#define INVERT_E2_DIR false
#define INVERT_E3_DIR false
#define INVERT_E4_DIR false
#define INVERT_E5_DIR false
#define INVERT_E6_DIR false
#define INVERT_E7_DIR false
#define X_HOME_DIR -1
#define Y_HOME_DIR -1
#define X_BED_SIZE 200
#define Y_BED_SIZE 200
#define X_MIN_POS 0
#define Y_MIN_POS 0
#define X_MAX_POS X_BED_SIZE
#define Y_MAX_POS Y_BED_SIZE
#define HOMING_FEEDRATE_MM_M { (50*60), (50*60) }
#define VALIDATE_HOMING_ENDSTOPS
#define EEPROM_CHITCHAT       // Give feedback on EEPROM commands. Disable to save flash.
#define EEPROM_BOOT_SILENT    // Keep M503 quiet and only give errors during first load
#define HOST_KEEPALIVE_FEATURE        // Disable this if your host doesn't like keepalive messages
#define DEFAULT_KEEPALIVE_INTERVAL 2  // Number of seconds between "busy" messages. Set with M113.
#define BUSY_WHILE_HEATING            // Some hosts require "busy" messages even during heating
#define PREHEAT_1_LABEL       "PLA"
#define PREHEAT_1_TEMP_HOTEND 180
#define PREHEAT_1_TEMP_BED     70
#define PREHEAT_1_TEMP_CHAMBER 35
#define PREHEAT_1_FAN_SPEED     0 // Value from 0 to 255
#define PREHEAT_2_LABEL       "ABS"
#define PREHEAT_2_TEMP_HOTEND 240
#define PREHEAT_2_TEMP_BED    110
#define PREHEAT_2_TEMP_CHAMBER 35
#define PREHEAT_2_FAN_SPEED     0 // Value from 0 to 255
#define PRINTJOB_TIMER_AUTOSTART
#define LCD_LANGUAGE en
#define DISPLAY_CHARSET_HD44780 JAPANESE
#define LCD_INFO_SCREEN_STYLE 0
#if DGUS_UI_IS(MKS)
  #define USE_MKS_GREEN_UI
#elif DGUS_UI_IS(IA_CREALITY)
#endif
#define SOFT_PWM_SCALE 0
#define NUM_SERVOS 1 // Note: Servo index starts with 0 for M280-M282 commands
#define SERVO_DELAY { 300 }

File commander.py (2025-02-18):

import sys
import signal
import numpy as np
import pyautogui as pg

from PIL import Image
from time import time, sleep

from multiprocessing import Process, Queue, Value, set_start_method

import matplotlib.pyplot as plt

from utilites import map_coords

from gesture_recognizer import GestureRecognizer
from generator import Generator
from interface import App
from drawer import Drawer
from string import punctuation

import speech_recognition as sr
from googletrans import Translator


pg.FAILSAFE = False


def remove_punctuation(s):
    res = ''
    for c in s.lower():
        if c not in punctuation:
            res += c
    return res.replace(' ', '_')


class Commander:
    def __init__(
        self, 
        frames_queue: Queue, 
        commands_queue: Queue, 
        images_queue: Queue,
        api_url: str,
        canvas_w, canvas_h, 
        shiftx, shifty,
        flag_recognition, flag_recognition_result,
        stop,
        flag_start,
        cpp_path: str, 
        lib_folder: str, 
        video_id: int,
        flag_end_plotting,
        cuda_version: str = '12.5', 
        gpu_arch: str = '86',
        port: str = '/dev/ttyACM0',
        baudrate: int = 115200,
    ):
        self.frames_queue = frames_queue
        self.commands_queue = commands_queue
        self.images_queue = images_queue
        
        self.api_url = api_url
        
        self.flag_recognition = flag_recognition
        self.flag_recognition_result = flag_recognition_result
        
        self.canvas_w = canvas_w
        self.canvas_h = canvas_h
        
        self.shiftx = shiftx
        self.shifty = shifty
        
        self.stop = stop
        self.flag_start = flag_start
        self.cpp_path = cpp_path
        self.lib_folder = lib_folder
        self.video_id = video_id
        self.flag_end_plotting = flag_end_plotting
        self.cuda_version = cuda_version
        self.gpu_arch = gpu_arch
        self.port = port
        self.baudrate = baudrate
        
        self.reset_flags()

        
    def reset_flags(self):
        self.flag_recognition.value = 0
        self.flag_recognition_result.value = 0
        self.stop.value = 0
        self.flag_start.value = 0
        self.flag_end_plotting.value = 0
        self.flag_drawing = False
        self.flag_end = False
        self.flag_reset = True
        self.flag_drawing_line = False
        self.last_showed_end_time = -1
        self.gestures_in_row = {
            'clean': 0,
            'end': 0,
            'drag': 0
        }
    
    def move_while(self, cond: callable, check_gestures = False, delay = 3):
        tm = time()
        while cond():
            if self.frames_queue.empty():
                continue
            
            recognition_results = self.frames_queue.get()
            
            if recognition_results.landmarks is None:
                continue
            
            fx, fy = (recognition_results.landmarks[0, 8, :2] + recognition_results.landmarks[0, 4, :2]) / 2
            fx = recognition_results.image.shape[1] - fx * recognition_results.image.shape[1]
            fy *= recognition_results.image.shape[0]
            if check_gestures and (('Thumb_Up' in recognition_results.gestures and time() - self.last_showed_end_time > delay) or ('Thumb_Down' in recognition_results.gestures and time() - self.last_showed_end_time > delay)):
                self.last_showed_end_time = time()
                return 'Thumb_Up' in recognition_results.gestures
            self.move(recognition_results.gestures, fx, fy, recognition_results.image.shape[:2])
        return None
        
    def listen(self):
        recognizer = sr.Recognizer()
        translator = Translator()
        while not self.flag_recognition_result.value:
            self.flag_recognition_result.value = 0
            self.flag_recognition.value = 0
            with sr.Microphone() as source:
                recognizer.adjust_for_ambient_noise(source)
                self.commands_queue.put(('print_text', ('Говорите...', )))
                audio = recognizer.listen(source, phrase_time_limit=5)
            try:
                self.commands_queue.put(('print_text', ('Идет распознавание...', )))
                text = recognizer.recognize_google(audio, language='ru-RU')
            except sr.exceptions.UnknownValueError as e:
                self.commands_queue.put(('print_text', ('Распознавание не удалось. Попробуйте ещё раз.', )))
                tm = time()
                self.move_while(lambda: time() - tm <= 2)
                continue
            self.commands_queue.put(('print_text', ('Идет перевод...', )))
            text_en = translator.translate(text, src='ru', dest='en').text
            # text, text_en = 'ананас', 'pineapple'
            print(text_en)
            self.commands_queue.put(('print_text', (f'Вы сказали: {text}?', )))
            self.commands_queue.put(('check_recognition', None))
            result = self.move_while(lambda: not self.flag_recognition.value, check_gestures=True)
            if result is not None:
                self.flag_recognition_result.value = int(result)
        return text, text_en
    
    def move(self, gestures, x, y, image_size):
        delta = 50
        w, h = pg.size()
        imgw, imgh = image_size
        
        xm = map_coords(x, 0, imgh, 0, w + delta / 2)
        ym = map_coords(y, 0, imgw, 0, h + delta / 2)
        
        if 'Click' in gestures: 
            pg.moveTo(xm, ym, 0.0, _pause=False)  
            if not self.flag_drawing_line:
                pg.click()
                self.flag_drawing_line = True
        elif 'Pointing_Up' in gestures:
            pg.moveTo(xm, ym, 0.0, _pause=False)
            self.flag_drawing_line = False
        else:
            self.flag_drawing_line = False
        
    def draw(self, gestures: list, x: int, y: int, image_size: tuple):
        imgw, imgh = image_size
        w, h = pg.size()
        x = imgh - x
        
        xc = map_coords(x, 0, imgh, -self.shiftx.value, self.canvas_w.value)
        yc = map_coords(y, 0, imgw, -self.shifty.value, self.canvas_h.value)
        self.move(gestures, x, y, image_size)
        if 'Click' in gestures and self.flag_drawing: 
            if xc > w * 0.2:   
                if not self.flag_drawing_line:      
                    self.commands_queue.put(('set_start', [(xc, yc)]))
                else:
                    self.commands_queue.put(('draw_line', [(xc, yc)]))
        elif 'Pointing_Up' in gestures or ('Click' in gestures and not self.flag_drawing):
            if xc > w * 0.2:
                self.commands_queue.put(('end_line', None))
        elif self.flag_drawing and gestures.count('Open_Palm') == 2:
            self.commands_queue.put(('delete', None))
        else:
            if 'Thumb_Up' in gestures and time() - self.last_showed_end_time > 3: 
                if not self.flag_drawing:
                    self.flag_drawing = True
                    self.flag_drawing_line = False
                    self.last_showed_end_time = time()
                    self.commands_queue.put(('remove_instructions', None))
                    self.commands_queue.put(('remove_img', None))
                    self.commands_queue.put(('change_status', None))
                else:
                    self.flag_end = True
                    self.last_showed_end_time = time()
                    self.flag_drawing = False
                    self.commands_queue.put(('change_status', None))
                    
        
    def loop(self):
        self.generation_queue = Queue()
        self.generator = Generator(self.generation_queue, self.commands_queue)
        
        self.drawer = Drawer(
            self.stop,
            self.flag_start,
            self.images_queue,
            self.cpp_path, 
            self.lib_folder, 
            self.video_id,
            self.flag_end_plotting,
            self.cuda_version, 
            self.gpu_arch,
            self.port,
            self.baudrate,
        )
        while not self.terminate_flag:
            if self.frames_queue.empty():
                continue
            
            recognition_results = self.frames_queue.get()
            
            if recognition_results.landmarks is None:
                continue
            
            fx, fy = (recognition_results.landmarks[0, 8, :2] + recognition_results.landmarks[0, 4, :2]) / 2
            fx *= recognition_results.image.shape[1]
            fy *= recognition_results.image.shape[0]
            self.draw(recognition_results.gestures, fx, fy, recognition_results.image.shape[:2])
            if self.flag_end:
                text_ru, text_en = self.listen()
                self.commands_queue.put(('delete_questions', None))
                self.generate(text_ru, text_en)
                self.plot(text_en)
                self.commands_queue.put(('change_status', None))
                self.commands_queue.put(('print_text', (f'', )))
                if self.flag_reset:
                    self.commands_queue.put(('reset_image', None))
                self.commands_queue.put(('remove_img', None))
                self.reset_flags()
                
    def generate(self, text_ru: str, text_en: str):
        self.commands_queue.put(('print_text', (f'Подождите, идёт генерация по запросу {text_ru}...', )))
        self.commands_queue.put(('setup_progressbar', None))
        self.commands_queue.put(('return_image', None))
        self.move_while(lambda: self.images_queue.empty())
        image = np.array(self.images_queue.get())
        
        self.generator.start_generation(image, text_en)
        self.move_while(lambda: self.generation_queue.empty())
        self.gen = self.generation_queue.get()

        self.commands_queue.put(('display', (self.gen, )))
        self.commands_queue.put(('remove_progressbar', None))
        self.commands_queue.put(('print_text', (f'Выберите изображение', )))
    
    def plot(self, prompt):
        self.move_while(lambda: self.images_queue.empty())
        self.commands_queue.put(('print_text', (f'Подождите, изображение обрабатывается...', )))
        image_idx = self.images_queue.get()
        image = self.gen[image_idx]
        image.save('images/generated/' + remove_punctuation(prompt) + '.png')
        
        self.commands_queue.put(('display_one', (image, )))
        self.drawer.start(np.array(image))
        
        self.move_while(lambda: self.images_queue.empty())
        self.commands_queue.put(('display_two', ([Image.fromarray((self.images_queue.get() * 255).astype('uint8')), image], )))
        self.commands_queue.put(('print_text', (f'Вам подходит то, что получится?', )))
        self.commands_queue.put(('check_recognition', None))
        self.flag_recognition.value = 0
        self.flag_recognition_result.value = 0
        res = self.move_while(lambda: not self.flag_recognition.value, check_gestures=True)
        self.commands_queue.put(('delete_questions', None))
        if res is not None:
            self.flag_recognition_result.value = res
        if not self.flag_recognition_result.value:
            self.flag_reset = False
            self.flag_start.value = 2
            return
        self.commands_queue.put(('print_text', (f'Пожалуйста, маркер в держатель и покажите большой палец.', )))
        res = self.move_while(lambda: True, check_gestures=True)
        self.flag_start.value = 1
        self.commands_queue.put(('print_text', (f'Подождите, пока ваше изображение нарисуется...', )))
        while True:
            self.flag_end_plotting.value = 0
            ret = self.move_while(lambda: not self.flag_end_plotting.value, check_gestures=True, delay=60)
            if ret is not None:
                if not ret:
                    self.stop.value = 1
                    break
            else: break
                
        self.commands_queue.put(('print_text', (f'Готово!', )))
        
        tm = time()
        self.move_while(lambda: time() - tm <= 3)
    
    def terminate(self):
        self.terminate_flag = True
        if self.process.is_alive():
            self.process.join(timeout=1)
            if self.process.is_alive():
                self.process.terminate()
                self.process.join()
        
    def start(self):
        self.terminate_flag = False
        self.process = Process(target=self.loop)
        self.process.start()
        
    def join(self):
        self.process.join()
        
if __name__ == '__main__':
    set_start_method('spawn')
    
    canvas_w = Value('i', 0)
    canvas_h = Value('i', 0)
    
    shiftx = Value('i', 0)
    shifty = Value('i', 0)
    
    flag_recognition = Value('i', 0)
    flag_recognition_result = Value('i', 0)
    
    stop = Value('i', 0)
    flag_start = Value('i', 0)
    
    frames_queue = Queue(-1)
    commands_queue = Queue(-1)
    images_queue = Queue(-1)
    
    cpp_path = 'trajectory.cpp'
    lib_folder = 'lib'
    second_video_id = 2
    flag_end_plotting = Value('i', 0)
    cuda_version = '11.8'
    gpu_arch = '86'
    port = '/dev/ttyACM0'
    baudrate = 115200
    
    api_url = 'https://qtf4vqzx-5000.euw.devtunnels.ms/generator'
    
    gesture_recognizer = GestureRecognizer(frames_queue, mode='tensorrt', recognizer_path='mlmodels/static_tftrt')
    app = App()
    com = Commander(
        frames_queue, 
        commands_queue, 
        images_queue,
        api_url,
        canvas_w, canvas_h, 
        shiftx, shifty, 
        flag_recognition, 
        flag_recognition_result,
        stop,
        flag_start,
        cpp_path, 
        lib_folder, 
        second_video_id,
        flag_end_plotting,
        cuda_version, 
        gpu_arch,
        port,
        baudrate,
    )

    
    gesture_recognizer.start_loop()
    com.start()
    
    def cleanup(signum, frame):
        print("Cleaning up resources...")
        com.terminate()
        app.running = False
        gesture_recognizer.terminate()
        frames_queue.close()
        commands_queue.close()
        frames_queue.join_thread()
        commands_queue.join_thread()
        sys.exit(0)
    
    signal.signal(signal.SIGINT, cleanup)
    signal.signal(signal.SIGTERM, cleanup)
    
    try:
        app.mainloop(
            frames_queue, 
            commands_queue, 
            images_queue,
            canvas_w, canvas_h, 
            shiftx, shifty, 
            flag_recognition, flag_recognition_result
        )
    except KeyboardInterrupt:
        cleanup(None, None)
    gesture_recognizer.join()
    com.join()
        

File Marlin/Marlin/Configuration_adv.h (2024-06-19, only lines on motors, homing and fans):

#define E0_AUTO_FAN_PIN -1
#define E1_AUTO_FAN_PIN -1
#define E2_AUTO_FAN_PIN -1
#define E3_AUTO_FAN_PIN -1
#define E4_AUTO_FAN_PIN -1
#define E5_AUTO_FAN_PIN -1
#define E6_AUTO_FAN_PIN -1
#define E7_AUTO_FAN_PIN -1
#define CHAMBER_AUTO_FAN_PIN -1
#define COOLER_AUTO_FAN_PIN -1
#define HOMING_BUMP_MM      { 5, 5 }       // (linear=mm, rotational=°) Backoff from endstops after first bump
#define HOMING_BUMP_DIVISOR { 2, 2 }       // Re-Bump Speed Divisor (Divides the Homing Feedrate)
#define MICROSTEP_MODES { 16, 16, 16, 16, 16, 16 } // [1,2,4,8,16]

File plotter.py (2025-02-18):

import os
import serial
from time import sleep
import mediapipe as mp
from math import cos, acos, pi
import cv2
from multiprocessing import Process, Value
from keras.models import load_model
from gesture_recognizer import BaseOptions, HandLandmarker, HandLandmarkerOptions, VisionRunningMode

class HandChecker:
    def __init__(
        self, 
        video_id, 
        pause, 
        landmarker_path = 'mlmodels/hand_landmarker.task',
        running_mode = 'VIDEO'
    ):
        self.video_id = video_id
        self.pause = pause
        self.landmarker_path = landmarker_path
        self.running_mode = running_mode
    
    def start_loop(self):
        self.terminate_flag = False
        self.process = Process(target=self.loop, daemon=True)
        self.process.start()
    
    def terminate(self):
        self.terminate_flag = True
        if self.process.is_alive():
            self.process.join(timeout=1)
            if self.process.is_alive():
                self.process.terminate()
                self.process.join()
    
    def loop(self):
        self.video = cv2.VideoCapture(self.video_id)
        timestamp = 0
        options = HandLandmarkerOptions(
            base_options=BaseOptions(model_asset_path=self.landmarker_path, delegate=1),
            num_hands=2,
            running_mode=getattr(VisionRunningMode, self.running_mode)
        )
        
        self.landmarker = HandLandmarker.create_from_options(options)
        while not self.terminate_flag:
            flag, img = self.video.read()
            
            if not flag:
                print("Can't read image")
                continue
            
            timestamp += 1
            
            img = cv2.cvtColor(img, cv2.COLOR_BGR2RGB)
            
            mediapipe_image = mp.Image(image_format=mp.ImageFormat.SRGB, data=img)
            detection = self.landmarker.detect_for_video(mediapipe_image, timestamp)
            
            self.pause.value = int(bool(detection.hand_landmarks))
            

def calculate_distance(ax, ay, bx, by):
    """
    Вычисляет расстояние между двумя точками.
    
    :param ax: Координата X первой точки.
    :param ay: Координата Y первой точки.
    :param bx: Координата X второй точки.
    :param by: Координата Y второй точки.
    :return: Расстояние между точками.
    """
    return ((ax - bx) ** 2 + (ay - by) ** 2) ** 0.5
        

class Plotter(serial.Serial):
    def __init__(self, video_id, stop, speed = 8000, *args, **kwargs):
        port = kwargs['port']
        os.system(f'echo Dragon2009 | sudo -S chmod 666 {port}')
        super(Plotter, self).__init__(*args, **kwargs)
        sleep(2)
        self.write_command('G90')
        
        self.stop = stop
        
        self.video_id = video_id
        self.pause = Value('i', 0)
        self.down = 100
        self.speed = speed
        self.prev_angle = 0
        
    def write_command(self, command: str):
        command += '\n'
        self.write(command.encode())
        return self.read_until(b'ok\n').decode()
    
    def servo(self, angle):
        self.write_command('M400')
        return self.write_command(f'M280 P0 S{angle}')
    
    def get_desired_angle(angle):
        angle = angle / 180 * pi
        desired = acos((cos(angle) * 15 - 18) / 15)
        return desired / pi * 180
        
    def calibrate_servo(self):
        angle = 0
        self.servo(0)
        self.move_to(500, 0, 16000)
        while True:
            self.servo(angle)
            angle += 5
            status = self.write_command('M119')
            state = status[status.rfind('x_min: ') + 7:status.find('\n', status.rfind('x_min: '))]
            if state == 'TRIGGERED' or angle == 180:
                break
        desired = Plotter.get_desired_angle(angle)
        self.down = desired
        self.move_to(0, 0, 16000)
        self.servo(0)
        
    def control_servo(self, command: str):
        """
        Управляет сервомотором на основе команды.
        
        :param ser: Объект Serial для связи с устройством.
        :param command: Команда ('up', 'maxup', 'down').
        """
        angle = 0
        if command == 'up': angle = 90
        elif command == 'maxup': angle = 0
        elif command == 'down': angle = self.down
        ret = self.servo(angle)
        sleep(abs(self.prev_angle - angle) * 0.002)
        self.prev_angle = angle
        return ret
    
    def generate_gcode(self, trajectory: list):
        """
        Генерирует G-код на основе траектории движения.
        
        :param trajectory: Список координат траектории.
        :return: Список команд G-кода.
        """
        i = 2
        gcode_commands = [(trajectory[0][0], trajectory[0][1], self.speed * 2), 'down']
        while i < len(trajectory):
            while i < len(trajectory) and trajectory[i][0] != 1e9:
                if abs(trajectory[i][0]) != 1e9:
                    gcode_commands += [(trajectory[i][0], trajectory[i][1], self.speed)]
                i += 1
            gcode_commands += ['up']
            if i < len(trajectory) - 1 and abs(trajectory[i + 1][0]) != 1e9:
                gcode_commands += [(trajectory[i + 1][0], trajectory[i + 1][1], self.speed * 2)]
            gcode_commands += ['down']
            i += 3
        return gcode_commands
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

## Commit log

2024-04-10 Инициализация репозитория
    [A137-Vysokotochnaya-prokladka-_-5_3-_-8.STEP, A172-Standartnyy-plastikovyy-rolik-dlya-V_paza.STEP, A181-Podshipnik-625rs_-_-5-_-16.STEP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]
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2024-04-15 Удалил накопившийся файловый мусор
    [M49-Soedinitel-40kh60.STEP]
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2024-04-16 Более-менее разобрался с cython и написал дозаполнение картинки
2024-04-16 Вернул необходимые для сборки файлы
    [M49-Soedinitel-40kh60.STEP]
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2024-04-16 Добавил папку на печать
    [Держатель маркера.stl]
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2024-04-17 Перестраиваю сборку под новую каретку, добавил крепление серве
2024-04-23 Сделал коррекцию каретки пружинами на кронштейнах сверху
    "\320\232\321\200\321\216\320\272.m3d"
    "\320\237\321\200\321\203\320\266\320\270\320\275\320\260.m3d"
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2024-04-23 Добавил пружины и кронштейны (высокие)
    [Крепление для держателя.stl]
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2024-05-02 Добавил крепления для пружин пониже; переделал отверстия под вплавляемые гайки; добавил дуржатель пружин
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2024-05-05 Изменил серву и крепление для него
    [Пластина для сервопривода.stl]
2024-05-05 Добавил чертежи деталей из фанеры
    [Каретка-втулки.dxf, Каретка.dxf, Пластина для пружин.dxf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]
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2024-05-05 Готовы отверстия, без проверки в реале
    [Пластина для сервопривода.stl]
2024-05-05 Поменял чертежи
    [Каретка-втулки.dxf, Каретка_эксцентрики.dxf, Пластина_для_пружин.dxf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]
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2024-05-07 Переименовал файлы с чертежами плюс добавил файл сервы
    [Каретка-втулки 3мм.dxf, Каретка_эксцентрики 3мм.dxf, Пластина_для_пружин 6мм.dxf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]
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2024-05-12 Изменил шкивы на 6мм ремень, добавил ушки для ремня в каретку, подправил фанерки под ремень
    [GT2 Belt.step, GT2 Idler Pulley, Configurable, Pulleys Lined Up in Assembly.STEP, GT2_20T.STEP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]
2024-05-13 Написал код по проверке пересечений, работоспособность не определена
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2024-05-15 Добавил пластинки для крепления видеокарты и их чертежи
    [Пластина_райзер_верх.dxf, Пластина_райзер_вырез.dxf]
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2024-05-17 Поменял пластины для крепления райзера и кабель-канала
    [Пластина_кабель-канал.dxf]
2024-05-18 Переписал код по заливке на последовательности, начал тесты с кругом
2024-05-20 Написал код по траектории, основывающийся на выборе нужной стороны
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2024-05-20 Запустил код на linux, попробовал генерировать другие объекты
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2024-05-24 Переделки в коде
    [Configuration.h]
2024-05-24 Поработал
    [Configuration.h]
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2024-05-30 Revert "Переместил cython-файлы"
    This reverts commit b00e1ce275ae19fe2be53c33001fdb43eafc5ae7.
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2024-06-03 Раскидал функции по разным файлам, чтобы не засорять main + переделки в нем
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2024-06-03 Сделал рабочим перенос файлов cython в отдельную папку
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2024-06-03 Перенес модели, которые лежали в корне папки
    [M49-Soedinitel-40kh60.STEP]
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2024-06-07 Дописал траекторию. Начал разбираться с ctypes, пока не доделал аппроксимацию.
2024-06-08 Сделал взаимодейстиве плюсов и питона в траектории. Нужно дописать путь.
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2024-06-12 Измененены детали
    [Держатель маркера.stl, Каретка-втулки 3мм.dxf, Крепление для держателя.stl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]
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2024-06-17 Траектория работает на произвольных изображениях. Сделал вывод цветов по-другому, обработал ошибки с памятью CUDA.
2024-06-17 Сборка чемодана
    [Пластина для сервопривода.stl]
2024-06-19 Перекинул марлин
    [Configuration.h, Configuration_adv.h, esp32.csv]
2024-06-19 Изменения в конфиге марлина
    [Configuration.h]
2024-06-19 Вернул марлин обратно(
    [Configuration.h, Configuration_adv.h, esp32.csv]
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2024-06-19 Сделал чтобы серва нормально работала
    [Configuration.h, Configuration_adv.h]
2024-06-19 Я заставил его рисовать (исправил ошибку)
    [interface.py, test_hands.py]
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2024-06-21 Обновление документов
    [Держатель маркера.stl]
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2025-02-03 Восстановил сборку плоттера, разнес модели по папкам
    [A137-Vysokotochnaya-prokladka-_-5_3-_-8.STEP, A172-Standartnyy-plastikovyy-rolik-dlya-V_paza.STEP, A181-Podshipnik-625rs_-_-5-_-16.STEP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]
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2025-02-15 Добавил файлы защелки v1 на печать
    [Держатель маркера 2_0.stl, Защелка для держателя.stl]
2025-02-16 Добавил мяса в держатель
    [Держатель маркера 2_0.stl, Защелка для держателя.stl]
2025-02-16 Добавил зацеп на защелку
    [Держатель маркера 2_0.stl, Защелка для держателя.stl]
2025-02-16 Увеличил зацеп, добавил крепление
    [Держатель маркера 2_0.stl, Защелка для держателя.stl]
2025-02-16 Скорректировал крепление для оси
    [Держатель маркера 2_0.stl, Защелка для держателя.stl]
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2025-03-18 Делаю корпус, коробка для ноута
    [Пластина_подвижная 4мм.dxf]
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2025-03-23 Добавил аккум, начал делать шип-пазы
    [KUKA_KiPo 6S1P 16000mAh.STEP]
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2025-03-26 Добавил arduino, скорректировал крепления (шип-пазы)
    [Base.stl, Machine.stp]
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2025-03-30 Доделал каркас, добавил чертежи
    [Боковая стенка 6.dxf, Боковое крепление видеокарты 4.dxf, Боковое крепление стабилизатора 4.dxf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]
2025-03-30 Добавил стлки
    [Base.stl, Крепление блока питания ноутбука.stl, Крепление хаба.stl]
2025-03-30 Подправил чертежи
    [Коробка нижняя 4.dxf]
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2025-04-02 Изменил держатели
    [Крепление блока питания ноутбука.stl, Крепление хаба.stl]
2025-04-08 Куча чертежей
    [Боковое крепление видеокарты 4.dxf, Крепление стабилизатора 4.dxf, Крепление стабилизатора рахъем 4.dxf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]
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2025-04-12 Занижение
    [Боковая стенка 6.dxf, Верхняя пластина.dxf]
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

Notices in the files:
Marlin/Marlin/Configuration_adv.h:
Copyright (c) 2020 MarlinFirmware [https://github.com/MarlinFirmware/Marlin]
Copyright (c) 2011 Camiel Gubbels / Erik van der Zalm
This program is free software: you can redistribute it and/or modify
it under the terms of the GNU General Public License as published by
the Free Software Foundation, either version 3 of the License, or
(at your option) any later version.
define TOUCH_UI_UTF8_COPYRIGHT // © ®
